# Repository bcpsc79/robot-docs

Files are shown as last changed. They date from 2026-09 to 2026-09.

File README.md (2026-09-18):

# BCPSC Robot

## 1. Project Overview

### 1.1 Description
The BCPSC Robot is a humanoid robot powered by AI, created by students from Bogura Cantonment Public School and College (BCPSC). Designed to act as an intelligent, interactive representative of the school, it can answer questions about BCPSC using a custom knowledge base, hold bilingual conversations (English and Bangla), recognize familiar faces, make eye contact, and use hand gestures.

### 1.2 Goals & Objectives
- Create an intelligent representative of BCPSC capable of answering questions using school data.
- Develop real skills in AI, robotics, electronics, and 3D design.
- Produce a fully functional humanoid robot to showcase student-led engineering in Bangladesh.
- Demonstrate that advanced robotics and AI are achievable with limited resources and strong determination.

### 1.3 Key Features
- **Bilingual Conversation:** Understands and speaks both English and Bangla natively using offline speech recognition models.
- **Face Recognition & Eye Tracking:** Uses real-time face detection to track faces and simulate natural gaze behavior.
- **Institutional Knowledge (RAG):** Answers questions specifically about BCPSC using a structured Retrieval-Augmented Generation dataset.
- **Natural Physical Expression:** Features a five-fingered hand with 20+ gestures, a physics-based moving jaw, and active eye servos.
- **AI Brain:** Runs a FastAPI microservice using Gemini's function-calling API to dynamically select tools (school lookup, news, hardware control).

---

## 2. Directory Structure & Documentation
This repository is organized into a pure file structure to separate domains. Each folder contains its own `README.md` documenting its architecture, challenges, solutions, learnings, and future improvements:

- **[`/Software/`](./Software/README.md)** - Documentation for the Raspberry Pi 5 vision, speech, AI brain, and API microservice.
- **[`/Firmware/`](./Firmware/README.md)** - Documentation for the C++ code running on the ESP32 and ESP8266 microcontrollers.
- **[`/Electronics/`](./Electronics/README.md)** - Documentation for the veroboard power distribution and voltage schemas.
- **[`/Mechanical Design/`](./Mechanical%20Design/README.md)** - Documentation for the 3D models and hybrid structural design.

---

## 3. Team & Contributions

- **Raiyan Bin Rashid:** Software Lead & AI System Development
- **Jotirmoy Bhowmik:** Software & System Integration
- **Farsad E Hossain:** Hardware Architecture, 3D Design & Mechanical Preparation
- **Naif Bin Nasim:** Hardware & Power Distribution
- **Fairuz Lubna Karim:** Visual Design & Presentation
- **Nahin Rahman:** Hardware Support

---

## 4. Project Timeline (211 Days)

- **Phase 1: Research & Planning (July - Aug 2025)** - Studied EZ-Robot/InMoov, defined robot capabilities, planned the 5-layer architecture.
- **Phase 2: Hardware Development (Aug - Oct 2025)** - Completed 3D modeling, printing, and assembly. Built the veroboard power system.
- **Phase 3: Software & AI Development (Sep - Dec 2025)** - Iterated Brain 1 (Ollama), Brain 2 (RAG & PostSTT), and Brain 3 (Gemini Function Calling API).
- **Phase 4: Integration & Testing (Nov 2025 - Jan 2026)** - Solved the audio feedback loop, connected Raspberry Pi to ESP32 over JSON protocol.
- **Phase 5: Optimization & Final Deployment (Jan - Feb 23, 2026)** - Codebase organized, docs written, ready for Science Fair exhibition.

---

## 5. Overarching Learnings
- **Continuous Coordination:** Because hardware and software were developed simultaneously, decisions in one domain constantly affected the other. The team learned to communicate changes across dependencies quickly and clearly.
- **Handling Leadership Gaps:** The team learned that a complex project doesn't pause when senior direction is unavailable; self-organization and peer-coordination are critical.
- **Ruthless Prioritization:** The requirement to have an exhibition-ready robot by a fixed date imposed discipline, teaching the team to defer non-essential improvements and focus purely on stability.

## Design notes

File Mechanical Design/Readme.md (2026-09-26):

# Mechanical Design Documentation

## Overview
The BCPSC Robot features a hybrid physical frame. Rather than an out-of-the-box kit, it is a custom-built chassis created by merging the best architectural qualities of two well-known open-source humanoid platforms: **EZ-Robot** and **InMoov**.
 
**Lead Mechanical Designer:** Farsad E Hossain

## Design Details

### 1. Hybrid 3D Printed Structure
- **Combining Platforms:** Because EZ-Robot and InMoov parts were not natively designed to fit together, the team redesigned joints, mounting points, and body proportions from scratch.
- **Iteration:** Creating a symmetrical, highly durable frame required multiple iterations of 3D modeling, test printing, and fit checking to ensure parts didn't collide.

### 2. Lower Base & Mobility
- **Weight Distribution:** The wheeled lower base was structurally designed and balanced to counter the high center of gravity generated by the humanoid upper torso and head.
- **Mobility:** Built around two DC motors with differential drive mechanisms to allow for pivoting and smooth forward motion.

### 3. Anatomical Features
- **Expressive Face:** The head houses an eye mechanism capable of panning and a jaw mechanism that physically simulates speech articulation.
- **Articulated Hand:** Features a fully assembled five-finger mechanical hand, structurally capable of performing over 20 distinct physical gestures.

## Challenges & Solutions
1. **Structural Merging:** Merging the two different platforms meant simple assembly wasn't an option. **Solution:** Complete structural redesign of the joints. Sustained rounds of physical fit testing were employed to correct imbalances before finalizing the printable files.

## Branches Reference
- `Components\3D Components\Robot 3d files`: Contains all the relevant 3D models and STL files used for printing.

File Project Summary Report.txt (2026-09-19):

Complete Project Summary Report
BCPSC Robot
Project Duration : 211 days

1

TABLE OF CONTENTS

2

1. INTRODUCTION

4

2. PROJECT OVERVIEW

5

3. PROJECT TIMELINE (211 DAYS BREAKDOWN)

6

4. SYSTEM ARCHITECTURE

7

5. PERSON -WISE CONTRIBUTIONS

11

6. TECHNICAL CHALLENGES FACED

14

7. SOLUTIONS & IMPROVEMENTS

15

8.

17

WHAT WE LEARNED FROM THIS PROJECT

9. FUTURE IMPROVEMENTS

20

10. CONCLUSION

21

1. INTRODUCTION
On July 27, 2025, a group of students from Bogura Cantonment Public School and College (BCPSC) started
building something unique for their school: a fully functional, AI -powered humanoid robot.
The BCPSC Robot was not created to meet a class requirement or copy an existing design. The team
believed that students from a school in Bogura, Bangladesh, could create something truly impressive. The
robot could recognize faces, understand speech in both
English and Bangla, respond intelligently to
questions, move its hands and eyes smoothly, and navigate its surroundings. This belief guided every
decision made over the next 211 days.
The goal of the project was to show that robotics and artificial intelligence are not just for well
-funded
research institutions or tech companies. By combining 3D
-printed hardware, open -source AI models,
locally hosted language systems, and custom electro
nics, the team aimed to prove that meaningful
engineering is achievable with limited resources, as long as there is enough determination and technical
skill.
The vision for the BCPSC Robot had three main objectives. First, to create a robot that could act as an
intelligent, interactive representative of the school, capable of answering questions about BCPSC's staff,
facilities, and institution using a knowledge base built specifically from school data. Second, to create a
platform for genuine learning, where each team member would develop real skills in areas they had never
explored before. Third, to produce something that could stand in an exhibition, showcasin
g both the
school and what student -led engineering in Bangladesh can achieve.
Bogura Cantonment Public School and College was the only sponsor and institutional supporter of this
project. Their support made the work possible, and the robot was designed from the start to carry the
institution's name and reputation.

3

2. PROJECT OVERVIEW
The BCPSC Robot is a humanoid robot powered by AI. It's designed to interact with people in a natural,
smart, and responsive way. It listens to questions in both English and Bangla, understands the inquiries,
and responds with speech. It recognizes familia r faces and greets them personally. It follows faces with
its eyes, moves its hands with gestures while speaking, and moves around using a wheeled base. When
asked about Bogura Cantonment Public School and College, including details about its staff, teache rs,
governing body, contact info, or institutional aspects, it answers from a structured knowledge base made
from BCPSC's own data. For general knowledge, current news, and questions outside the school
database, it connects through a layered AI system that can access online models when necessary and
works offline when the internet is not available.
In summary, the BCPSC Robot acts as an intelligent, bilingual, interactive assistant. It can hold
conversations, recognize who it is talking to, and represent its institution.

Key Features
The robot has several key features that set it apart from a basic demonstration project.
•

•

•

•

Bilingual conversation is central to its system. The robot understands and responds in both
English and Bangla. It uses offline speech recognition models for each language, running at the
same time in separate threads. The Bangla text -to-speech output uses a specific voice mode l for
natural-sounding speech.
Face recognition and eye tracking give the robot real awareness of the people in front of it.
YuNet face detection runs in real time on a Raspberry Pi 5. This information feeds into a
behavioral state machine that keeps the robot's eyes following whoever it looks at, complete with
blinkin g and subtle gaze shifts to make interactions feel more natural.
Institutional knowledge is managed through a Retrieval -Augmented Generation system based
entirely on BCPSC's own structured data. This includes staff lists, teacher information, governing
body records, and school contact details. The robot can accurately answer specific question s
about real people and departments without generating false information.
Natural physical expression comes from a five-fingered hand capable of over twenty different
gestures, a jaw that moves in a physics -based manner when speaking, and eye servos that move
smoothly per human gaze behavior. These parts are integrated with the AI system, allowing the
robot to gesture while talking and respond physically to its actions.

Hardware Summary
The robot's design is a hybrid created by analyzing and combining features from two open -source
humanoid platforms: EZ -Robot and InMoov. Every structural component was custom 3D modeled,
printed, tested, adjusted until the assembly met the team's standards for strength, symmetry, and
mechanical reliability.
The computing core operates on a Raspberry Pi 5 . This unit handles all AI processing, vision tasks,
speech recognition, and system coordination. A wheeled base provides mobility. It is controlled by an
ESP32 microcontroller that manages a PWM differential drive system, features a browser-based wireless
4

joystick interface, and has a hardware deadman switch that cuts motor power if the controller
disconnects.
Facial expressions are controlled by a second ESP32 , acting as the main controller. This device drives the
eye and jaw servos directly and sends hand gesture commands over WiFi to an ESP8266 , which manages
the five finger servos independently. The entire multi -microcontroller system communicates using serial
JSON commands and HTTP REST calls over a local WiFi network created by the ESP32.
Power is supplied through a custom -designed and hand -soldered veroboard circuit. This ensures the
correct voltage reaches every component, built from scratch to guarantee safe power delivery and circuit
reliability during operation.

Software Summary
The software architecture consists of five interconnected layers, from low -level motor control firmware to
cloud -connected AI services.
At the hardware level, C++ firmware on the ESP32 and ESP8266 microcontrollers manages all servo
control, motor operation, WiFi communication, and gesture execution. This is complex, with the eye
servo implementing four behavioral states (fixating, saccadin g, scanning, glancing) and employing
Exponential Moving Average smoothing and microsaccade simulation. The jaw's movement is based on a
physics model for realistic behavior.
The vision layer operates on the Raspberry Pi, using Python to create a detection -to-actuation pipeline.
This includes face detection with YuNet ONNX, face tracking with OpenCV's CSRT tracker, pose
estimation, gaze mapping, signal smoothing, and serial communication to th e servo controller, all
happening in a continuous real -time loop.
The speech layer runs two offline speech -to-text recognizers at once. It post-processes the recognized
text using fuzzy string matching to correct any misheard Bangla names and synthesizes responses using
offline text-to-speech models for both languages.
The AI brain evolved through three generations during the project. The final production version is a
FastAPI microservice built around Gemini's function -calling API. The language model automatically
selects the right tool —whether it's for a school database lookup, new s retrieval, web search, or weather—
based on user questions. This setup includes Redis caching, Server -Sent Events streaming for quick
responses, Prometheus metrics for monitoring, and a structured admin permission gate to prevent
hardware commands from ex ecuting without explicit authorization.
The school knowledge base is a structured dataset of BCPSC records, indexed by teacher’s name, role
and blood group . The dataset is collected from http://bcpsc.edu.bd/ It uses sentence -transformer
embeddings for semantic search with queries that do not match specific keywords.

5

3. PROJECT TIMELINE (~211 Days )
Phase 1: Research & Planning (July 27

– August 2025)

•

Studied existing humanoid robots (EZ -Robot, InMoov) to design a hybrid structure.

•

Defined robot capabilities: bilingual speech, face recognition, school knowledge, and physical
gestures.

•

Planned the five -layer architecture guiding hardware and software development.

Phase 2: Hardware Development (August

– October 2025)

•

Farsad completed 3D modeling, printing, and assembly of hybrid humanoid structure.

•

Naif built and soldered the custom veroboard power distribution system.

•

Nahin assisted with hardware installation, integration, and troubleshooting.

•

Wheeled base, body, and mechanical modules fully assembled by late October.

Phase 3: Software & AI Development (September

– December 2025)

•

Brain 1: Initial AI with local Ollama model, basic movement control, and face recognition.

•

Brain 2: Added BCPSC knowledge base, PostSTTProcessor for Bangla names, and multi
response cascade.

•

Brain 3: Production microservice using Gemini function -calling, Redis caching, SSE streaming,
and admin confirmation for hardware commands.

•

Raiyan implemented full hand assembly and coding integration for gestures.

Phase 4: Integration & Testing (November 2025

– January 2026)

•

Connected Raspberry Pi AI to ESP32 master controller using reliable serial JSON protocol.

•

Resolved audio feedback loop between TTS and STT.

•

Finalized dual -language offline STT and Bangla TTS synthesis.

Phase 5: Optimization & Final Deployment (January

6

-source AI

– February 23, 2026)

•

Codebase organized with separate virtual environments; documentation written.

•

Robot ready for exhibition: fully functional, bilingual, expressive, face -tracking, and AI -driven.

4. SYSTEM ARCHITE CTURE
The BCPSC Robot is built across five interconnected layers, spanning physical hardware at the base
and an AI-driven software brain at the top. Every layer communicates with the layers immediately
above and below it, forming a continuous pipeline from physical sensing to intelligent response. The
overall architecture was designed around three guiding principles: offline-first operation, hardware
safety, and modular separation of concerns, so that any single subsystem can be tested, repaired, or
upgraded independently.

4.1 Hardware Architecture
Microcontrollers
The robot's hardware intelligence is split among three microcontrollers. Each one has a specific role to
avoid any single controller slowing things down.
The main microcontroller is an ESP32, which acts as the master controller for the robot's expressive
systems. It manages the eye and jaw servos, processes incoming serial JSON commands from the
Raspberry Pi, and sends gesture instructions to the hand contr oller over HTTP. It works in both AP and
STA WiFi mode, meaning it serves as a wireless access point for the hand controller while also
connecting to the wider network. All commands from the Raspberry Pi are processed using ArduinoJson
and sent to the corr ect subsystem —eye, jaw, or hand—with a 100-millisecond lockout period applied
after each serial command to avoid conflicts between the web and serial interfaces.
The second microcontroller is an ESP8266, which focuses solely on hand gesture control. It runs a REST
API on port 80 and manages five individual finger servos —thumb, index, middle, ring, and little finger —
each mapped to fixed open and closed angles based on actual hardware testing. The ESP8266 has a
static IP address so the ESP32 master can find it easily.
The third microcontroller is another ESP32, which handles the drive system. It creates a WiFi access
point and provides a browser -based dual -joystick controller interface to any connected device. It
controls two DC drive motors using PWM for differential d rive. It includes a hardware deadman switch: if
no device connects to its access point for more than 500 milliseconds, the motors stop immediately and
movement is disabled. This design prevents the robot from moving on its own or rolling if the operator
loses connection.
A Raspberry Pi 5 is positioned above the microcontroller layer and serves as the main processor for
vision and AI tasks. It communicates downward to the ESP32 master using serial USB and a structured
NDJSON command protocol with acknowledgment and retry lo gic.
Power System
The hardware team designed and built the power distribution system from the ground up. They created
a custom Veroboard circuit to organize all power connections safely and make sure each component
gets the right operating voltage. The system uses a series battery setup to provide the voltage levels
needed by the drive motors, while a buck converter lowers the voltage to s afer levels for the
microcontrollers and servo motors. Strict wiring practices were followed throughout, since one wrong
7

connection in such a complex circuit could damage the entire system. The team conducted multiple
tests to confirm connection integrity before attaching powered components.
Motors and Servos
The robot uses two DC motors for movement, controlled by an H -bridge driver. This setup allows
management of both direction and speed through four PWM pins. Steering is done via differential drive —
reducing the PWM output on one side compared to the other c auses the robot to turn while still moving
forward.
The eye servo pans left and right over a calibrated range, driven by an Exponential Moving Average
smoothing algorithm that adjusts its responsiveness based on the robot's current behavior, creating
natural -looking gaze movement instead of mechanical snapp ing. The jaw servo uses a physics -based
motion model with velocity accumulation and damping, resulting in realistic mouth movement during
speech. The five hand servos operate independently, each moving to precise angles to create distinct
gestures from a l ibrary of over twenty programmed positions.
Mechanical Structure
The physical body of the BCPSC Robot is a hybrid design based on two established open -source
humanoid platforms —EZ -Robot and InMoov. It combines the best structural features of each into one
unified frame. All structural components, custom brackets, and bo dy panels were designed in 3D
modeling software and printed through several iterations, with fit testing and dimensional adjustments
made along the way.
The bottom base was designed with a focus on weight distribution, as the humanoid upper body creates
a high center of gravity that needs to be balanced by the wheeled base for stable movement. The overall
assembly underwent multiple rounds of symmetry chec ks and structural reinforcement to ensure
smooth mechanical operation across all joints and moving parts .

4.2 Software Architecture
Speech -to-Text (STT)
The speech recognition system runs two simultaneous recognizers within a single audio capture loop.
This setup allows the robot to understand input in both English and Bangla, without needing the speaker
to announce their language beforehand. English recognition is managed by Vosk, utilizing a Kaldi
acoustic model that operates entirely offline. Bangla recognition works in a parallel daemon thread
using the BanglaSpeech2Text library, also offline. During startup, the system performs ambient no ise
calibration to set appropriate energy thresholds for the microphone. A key challenge encountered
during development was audio feedback, as the robot's own TTS output was detected by the
microphone as new speech input. Careful management of audio stream timing and the relationship
between playback and capture processes resolved this issue.
STT systems often mishear Bangla proper nouns. To address this, a dedicated PostSTTProcessor
processes every recognition output before it reaches the AI brain. This processor applies three correction
strategies in sequence: Levenshtein edit distance scorin g, SequenceMatcher longest -common 8

subsequence ratio, and optional semantic embedding matching using sentence transformers. The
combined score from these methods is weighted and compared against a threshold before the corrected
text is forwarded. This step is crucial for accurate name looku ps in the BCPSC staff database.

AI Brain
The AI brain has evolved through three distinct generations during the project. The first generation relied
on a fully offline Ollama local language model with a regex -based intent recognition engine that covered
nine intent types in English and Bangla Uni code patterns. While it was functional, it lacked awareness of
school -specific information.
The second generation introduced a structured knowledge base along with a multi -source response
method. The system first searches the BCPSC database, then attempts an offline knowledge layer of
hardcoded facts, and only calls the Gemini 2.0 Flash API as a last resort. Each response includes a source
label that shows which pipeline generated it, ensuring that the system's reasoning is transparent.
The third and current generation is built as a FastAPI microservice centered on Gemini's native function calling capability. Instead of pre -classifying every query in code, the language model reads the user's
input and creates a structured function call. I t selects from registered tools, including school database
lookup, news retrieval, web search, weather, and hardware device control. The microservice executes
the selected tool, sends the result back to the model, and the model provides the final natural -language
response. Hardware control commands are queued and need separate admin confirmation before
execution, ensuring a safety measure between the AI layer and the physical robot’s movement.
Retrieval -Augmented Generation (RAG)
The RAG system gives the robot accurate, grounded knowledge about BCPSC. The knowledge base
consists of structured JSON datasets that include staff rosters, teacher lists for both the school and
college sections, governing body members, and institutional c ontact details. At startup, the system
builds two in -memory indexes from this data: a role index that maps job titles to records and a name
index that maps lowercase names to records for quick lookups. If an exact match isn’t found, the system
uses semanti c search with sentence -transformer embeddings and cosine similarity scoring. This setup
allows common queries, like finding a teacher by name or retrieving contact information, to be
answered in milliseconds without any API call. Uncommon or unclear querie s still get meaningful
responses through semantic retrieval.
Text-to-Speech (TTS)
The TTS system supports voice output in both English and Bangla. Bangla synthesis uses the Coqui TTS
library with the mobassir94/bangla -tts model. A text cleaning pipeline removes all non -Bangla Unicode
characters before synthesis to prevent garbled output from mixed-script input. Synthesized audio is
cached using a hash of the cleaned text, meaning repeated phrases, like greetings and standard
responses, load instantly from cache rather than being re -synthesized. For higher -quality output, a
quantized GGUF Bangla TTS model runs through llama.cpp, striking a good balance between voice
9

quality and file size on limited hardware. Synthesis runs in a background thread to avoid blocking the
main conversation loop while generating audio.
Vision
The vision system comprises a multi -stage pipeline designed to operate at real -time speeds on the
Raspberry Pi 5. Frames from the camera are first sent to a YuNet face detector running as an ONNX
model, which functions at about ten to fifteen frames per se cond at 320 by 240 resolution. This
resolution was chosen after testing confirmed that 640 by 480 caused unacceptable latency on ARM
hardware. Between detection frames, a CSRT tracker keeps track of the last known face position,
preventing visual output fr om flickering when the detector misses a single frame.
A PersonSelector module identifies the most relevant face in scenes with several people. It uses face size,
proximity to the center of the frame, and tracking continuity for this purpose. A PoseEstimator then
derives the subject's approximate gaze directio n from facial landmark geometry. A GazeMapper
translates this into a target servo angle. A final smoothing filter —using a critically -damped model rather
than simple exponential smoothing, which caused servo oscillation —converts the mapped angle into a
stable command sent over serial to the ESP32.
The system maintains three behavioral states: active tracking when a face is detected, idle sweep with
randomized blink timing when no face is present, and a smooth return -to-center transition between the
two. Face recognition runs separately using DeepFac e with Facenet512, creating 512 -dimensional face
embeddings that are matched against a database of known individuals for identity identification.
Backend API
The backend operates as a FastAPI microservice that provides a versioned REST and streaming API for all
robot intelligence functions. The primary chat endpoint returns responses via Server -Sent Events
streaming, with a target latency of under 200 milliseco nds for cached queries. Redis caching, along with
an in-memory fallback, stores recent responses with short time -to-live values to avoid stale answers
while significantly speeding up repeated queries. Asynchronous parallel tool execution lets multiple
Gemini function calls run at the same time using Python's asyncio framework when the model requests
more than one tool at once. Prometheus metrics are available at a dedicated endpoint, tracking request
counts, latency histograms, and tool call frequency for o bservability. The entire service is containerized
using Docker Compose with a Redis sidecar, and Kubernetes manifests are available for production
deployment. A complete test suite includes unit tests with mocked Gemini responses and integration
tests that validate end -to-end latency against defined performance targets.

10

5. PERSON -WISE CONTRIBUTION
5.1 Raiyan Bin Rashid
Software Lead & AI System Development
Areas of Work:
•

Designed and implemented the full AI interaction pipeline (STT → AI processing → TTS)

•

Integrated Text -to-Speech with natural voice output

•

Built and rebuilt the Robot Brain system (multiple versions)

•

Implemented RAG for school -specific knowledge

•

Developed a FastAPI -based Robot Brain microservice with structured API endpoints

•

Connected vision tracking with eye movement control

•

Managed Raspberry Pi deployment and microcontroller communication

•

Made the full hand assembly and completed the hand movement coding

Major Contributions:
•

Modular AI system design for smooth real -time conversation

•

Reduced latency and improved response stability for live demos

•

Safety control before executing hardware commands

•

Structured system prompts with tone, limitations, and fallback behavior

Challenges:
•

Managing real-time listening and speaking without overlap

•

Handling noisy audio and misrecognized Bangla names

•

Preventing incorrect AI -generated information

•

Maintaining system stability during live demonstrations

5.2 Jotirmoy Bhowmik
Software & System Integration
Areas of Work:

11

•

Movement Control System (motor control logic and command execution flow)

•

Face Recognition System development and integration

•

Hardware –Software integration

•

Assisted in Body Assembly

•

Technical support to team members

Major Contributions:
•

Ensured stable and responsive movement control

•

Integrated face recognition for known person detection

•

Connected software with hardware so commands work correctly

Challenges:
•

Hardware -software synchronization

•

Multiple iterations for movement calibration

•

Optimizing real -time face recognition performance

•

Efficient system design with limited resources

5.3 Farsad E Hossain
Hardware Architecture, 3D Design & Mechanical Preparation
Areas of Work:
•

Full 3D modeling and structural design of robot body

•

3D printing of all structural and custom parts

•

Bottom base construction and wheel system design

•

Mechanical integration of all hardware modules

•

Architecture modification and structural improvements

Major Contributions:
•

Designed a hybrid structure from EZ -Robot and InMoov

•

Printed and modified custom parts for strength and fit

•

Constructed the bottom base with proper balance and weight distribution

•

Performed multiple testing rounds and structural corrections

Challenges:
•

Combining two robot structures into one cohesive system

•

Maintaining symmetry, durability, and smooth movement

•

Independent hardware preparation required careful problem -solving

5.4 Naif Bin Nasim
Hardware & Power Distribution
12

Areas of Work:
•

Robot movement hardware setup

•

Hand movement hardware support

•

Full power distribution system design and implementation

•

Hand -soldered veroboard circuit from scratch

Major Contributions:
•

Built a safe and organized power distribution system

•

Ensured correct wiring for all motors and components

•

Maintained circuit safety during testing

Challenges:
•

Small wiring errors could damage the circuit

5.5 Fairuz Lubna Karim
Visual Design & Presentation
Areas of Work:
•

Overall visual design of the robot

•

Preparing the robot for exhibition display

Major Contributions:
•

Made the robot presentable in the Science Fair 2025 at BCPSC

5.6 Nahin Rahman
Hardware Support
Areas of Work:
•

Assisted in hardware preparation and assembly

•

Helped with installation and troubleshooting

Major Contributions:
•

Supported hands -on hardware tasks

•

Helped complete hardware setup within project timeline

Challenges:
•
•

13

Limited guidance at times; team had to self -coordinate

6. TECHNICAL CHALLENGES FACED
Hardware Challenges
The biggest hardware challenge was merging two different open -source humanoid platforms, EZ -Robot
and InMoov, into one physical structure. These systems were not designed to work together, so
combining them required a complete redesign of joints, mounting points, and proportions instead of
just simple assembly. Keeping the structure symmetrical while ensuring durability and smooth
movement at all joints involved several rounds of 3D printing, physical testing, corrections, and
reprinting before the frame me t acceptable standards.
Software Challenges
The main software challenge was audio feedback. The robot's text -to-speech voice was being picked up
by the microphone and processed as new input, creating a loop that interrupted conversations. Solving
this issue needed careful timing and management of th e playback and capture processes. Another
related challenge was the consistent misrecognition of Bangla proper nouns by the speech -to-text
engine, which made name lookups against the BCPSC database unreliable until a dedicated correction
layer was created and integrated.
AI Challenges
The key AI challenge was stopping the language model from producing incorrect or made -up
information about BCPSC, including details about its staff and structure. Since general -purpose
language models lack specific knowledge about a school in Bogura, Bangl adesh, each school -related
response had to rely on the local knowledge base through RAG before reaching the model. Establishing
reliable confidence thresholds to determine when the RAG result was good enough and when to switch
to an online API required ext ensive tuning. Creating a system that detected intent and language equally
well in English and Bangla Unicode without misrouting queries added more complexity.
Power and Safety Issues
Designing a safe power distribution system for a robot with multiple microcontrollers, servo motors, and
DC motors, each needing different voltage and current, was a critical engineering task. A single wiring
error could damage the entire circuit. Several connection errors were found and fixed during testing
before the system was stable and safe. On the software side, a hardware deadman switch was included
in the drive system to automatically cut motor power if the wireless controller connection dropped,
preventing the robot from moving without an active operator.
Resource Limitations
The entire project operated under tight resource constraints. Hardware components, computing power,
and development time were limited, so every decision had real costs. Running computer vision tasks on
a Raspberry Pi 5 required careful choices about resolu tion—using 320 by 240 pixels instead of 640 by
480—because the higher resolution caused latency that made real -time tracking impossible on ARM
hardware. The need to maintain separate Python virtual environments due to conflicts among computer
vision, audio , and AI libraries added to the deployment complexity. Throughout the project, the team
14

consistently sought solutions that were not only functional but also lightweight and efficient enough to
run reliably on the available hardware.

7. Solutions & Improvements
7.1 How Problems Were Identified
Most problems in the BCPSC Robot project were identified through direct testing rather than theoretical
analysis. Hardware issues surfaced during physical assembly and powered testing rounds, where
incorrect wiring, poor servo calibration, or structural im balance produced immediate and observable
failures. Software issues emerged during live system runs — the audio feedback loop, for instance, was
not anticipated during design but became immediately apparent the first time TTS and STT ran
simultaneously. AI accuracy problems were discovered through test queries, where the language
model's tendency to generate plausible but incorrect information about BCPSC became clear as soon as
school -specific questions were asked. In each case, the team documented what fa iled, traced it to its
root cause, and built a targeted solution rather than applying broad workarounds.
7.2 How Problems Were Solved
The audio feedback problem was resolved by managing the timing relationship between the TTS
playback process and the STT microphone capture process, ensuring the recognizer was not actively
listening while the robot was speaking. The Bangla name misrecogni tion problem was solved by building
a dedicated PostSTTProcessor that applied three complementary string similarity algorithms
—
Levenshtein distance, SequenceMatcher ratio, and semantic embedding matching — in sequence,
correcting STT output before it rea ched any name lookup or database query. Hardware race conditions
between the serial interface and the web interface were resolved by implementing a 100 -millisecond
lockout window after every serial command, giving the hardware time to settle before accepti ng further
instructions. The eye -tracking flicker problem was solved by introducing a CSRT tracker running
between detection frames, maintaining continuity on the last known face position when the detector
momentarily failed. Power safety was addressed thr ough a purpose -built veroboard circuit with
organized, verified wiring, combined with a software deadman switch that cut motor power
automatically upon controller disconnection.
7.3 What Improved Over Time
The project showed consistent improvement in three areas. Response accuracy improved as the
knowledge base matured — early versions of the robot had no school -specific knowledge and would
fabricate answers, while later versions grounded every BCPSC -related response in verified data through
RAG. System stability improved as the serial communication protocol was hardened with ACK and retry
logic, and as audio pipeline timing was refined. Response speed improved through the introduction of
Redis caching, offli ne-first knowledge lookup, and audio caching for repeated TTS phrases, reducing
latency on predictable queries to near -instant levels.
7.4 Brain Version 1 to Version 3 Evolution
Brain Version 1 — was fully offline and deterministic. All user input passed through a regex -based intent
recognition engine that classified queries into one of nine intent types in both English and Bangla, then
15

routed each to a dedicated handler. Responses were generated by a local Ollama language model
running the Gemma 2B model on -device. This version was functional and required no internet
connection, but it had a fundamental limitation: the model had no knowl edge of BCPSC and would
produce confident but inaccurate answers to any school -specific question.
Brain Version 2 — addressed this by introducing a structured RAG knowledge base built from real BCPSC
data. A QueryClassifier detected the language and type of each query, routing it through a cascade —
first to the school database, then to an offline knowledge layer of har dcoded facts, then to Ollama for
enhancement, and finally to the Gemini API or News API when all local sources were insufficient. The
PostSTTProcessor was added at this stage to correct misheard Bangla names before they reached the
database. Each response carried a source and pipeline label so the system's reasoning path was always
transparent. The limitation of this version was that the code itself was still making all routing decisions
— the language model had no agency over which tool or data source to c onsult.
Brain Version 3 — resolved this by handing decision -making authority to the model itself through
Gemini's native function -calling API. Rather than the code pre -classifying every query, the model reads
the user's message and emits a structured function call selecting from r egistered tools — school
database lookup, weather, news, web search, and hardware device control. The microservice executes
the selected tool, returns the result, and the model produces the final response within a single streaming
cycle. This version added production infrastructure that the earlier versions lacked entirely: SSE
streaming for low -latency output, Redis caching, Prometheus observability metrics, an admin
confirmation gate for hardware commands, Docker containerization, and a full test suite. T he
progression across all three versions reflects the project's central lesson — begin with deterministic,
code-controlled logic to establish reliability, then progressively transfer agency to the model as the
infrastructure around it matures.

16

8. What We Learned From This Project
8.1 Technical Learning
Raiyan Bin Rashid — Software Lead
Raiyan's technical growth across the 211 days of this project was the most broad in scope, given that he
was responsible for every layer of the software stack. He developed practical proficiency in building
production -grade Python backend services using Fa stAPI, managing asynchronous programming with
asyncio, and structuring REST and streaming APIs for real -world deployment. He learned how Retrieval Augmented Generation works not as an abstract concept but as an engineering problem — how to
structure a know ledge base, build embedding indexes, tune confidence thresholds, and decide when
local retrieval is sufficient versus when to escalate to an online model. He gained hands -on experience
with the Gemini function -calling API and understood the fundamental dif ference between code controlled intent routing and model -controlled tool selection. His work across three generations of the
robot brain gave him direct experience in system evolution — understanding why an architecture that
works at one level of complexity breaks at the next, and how to rebuild thoughtfully rather than patch
repeatedly.
Jotirmoy Bhowmik — Software & Integration
Jotirmoy learned how motor control logic translates from code to physical behavior — that a PWM value
on a screen corresponds to a real force on a wheel, and that the relationship between the two requires
calibration, testing, and iteration. He gained prac tical experience in hardware -software integration,
understanding that the boundary between a microcontroller and a software system is not clean and
requires careful protocol design on both sides. His work on face recognition gave him exposure to
computer v ision pipelines, embedding -based identity matching, and the performance constraints of
running inference in real time on limited hardware.
Farsad E Hossain — Hardware & 3D Design
Farsad developed the most specialized technical skillset on the team. He learned professional 3D
modeling and structural design for robotics applications — not decorative modeling, but functional
design where every dimension affects whether a part fits, ho lds weight, and moves correctly. He learned
the full 3D printing workflow: designing for printability, accounting for material tolerances, identifying
structural weak points, and iterating through multiple versions of the same part until it performed
reliably. Studying EZ -Robot and InMoov gave him a working understanding of how established
humanoid platforms are engineered, and combining them into a hybrid structure taught him how to
evaluate, adapt, and improve existing designs rather than simply replicate them.
Naif Bin Nasim — Power & Electronics
Naif developed practical skills in electronics and circuit design that are difficult to acquire outside of a
real project with real consequences. He learned how to read and design power distribution circuits, how
to solder a veroboard from scratch, and how to organize a multi -component wiring system safely and
clearly. He learned how different components — microcontrollers, servo motors, DC motors — have
different voltage and current requirements, and how a distribution system must account for all of them
17

simultaneously. The testing phase, where connection mistakes were identified and corrected without
damaging the overall circuit, gave him direct experience in hardware fault diagnosis and safe
troubleshooting practice.
Nahin Rahman — Hardware Support
Nahin gained broad practical exposure to hardware assembly and installation across multiple systems,
developing hands -on familiarity with the physical construction of a complex robot. He learned how to
contribute effectively to a technical project without having primary ownership of any single system, and
how to identify problems and escalate them appropriately during testing.
8.2 Teamwork Learning
Coordination
The BCPSC Robot required hardware and software to be developed simultaneously by different people,
which meant that decisions made in one domain constantly affected the other. The team learned that
coordination in this kind of project is not a one -time planning activity but a continuous process. When
Farsad modified a structural dimension, it affected where Naif could route wiring, which affected where
Jotirmoy could place sensors, which affected what Raiyan could assume about camera positioning.
Learning t o communicate changes across these dependencies — quickly and clearly — was a skill the
team developed through necessity rather than instruction.
Task Distribution
Early in the project, task boundaries were not always clearly defined, which led to occasional duplication
of effort and gaps in ownership. Over time the team naturally settled into a structure where hardware
and software responsibilities were separated, a nd within each domain, individuals took clear ownership
of specific subsystems. This organic distribution proved effective because it matched each person's
emerging strengths to the work that needed doing, rather than assigning roles based purely on initia l
preference.
Handling Leadership Gaps
There were periods during the project when senior direction was limited and team members had to take
initiative without waiting for instruction. This was particularly noted in the hardware team, where
assembly and troubleshooting work continued through coo rdination among peers rather than top -down
management. The team learned that a project of this complexity does not pause when a leader is
unavailable, and that the ability to self -organize and make reasonable decisions independently is as
important as any technical skill.
Working Under Deadline
The requirement to have a working, exhibition -ready robot by a fixed date imposed a discipline on the
project that no internal process could have replicated. The team learned to prioritize ruthlessly —
deferring improvements that were desirable but not ess ential, and concentrating effort on whatever was
most likely to fail under exhibition conditions. They learned that a robot that works reliably at eighty
18

percent of its intended capability is more valuable at a demonstration than one that works brilliantly half
the time.
8.3 Personal Growth
Beyond technical skills and teamwork, the project produced a kind of personal growth in each member
that is harder to quantify but no less real. Every member of the team encountered problems they did not
know how to solve at the moment they encountered the m, and solved them anyway. Farsad completed
the entire mechanical construction independently, which required not just skill but sustained self reliance over months of work. Raiyan rebuilt the robot's AI brain three times, which required the
willingness to acknowledge that a previous version was insufficient and start again with a clearer
understanding. Naif worked in a domain where a single mistake could undo weeks of work, and learned
to carry that responsibility calmly. Jotirmoy operated at the boundary b etween two worlds — software
and hardware — where the rules of each domain sometimes conflict, and learned to navigate that
ambiguity without losing ground in either direction.
The project also gave the entire team a realistic understanding of what engineering actually involves. It
is not a linear process from idea to finished product. It is a repeated cycle of building, testing, failing,
understanding why, and building again — and the willingness to complete that cycle without losing
motivation is perhaps the most important thing any of them took away from the 211 days they spent
building the BCPSC Robot.

19

9. FUTUR E IMPROVEMENTS
9.1 More Natural Movement
The current movement system is functional but operates within visible mechanical constraints. Future
development should focus on making the robot's physical behavior feel more organic and less
predictable. This includes expanding the hand gesture library w ith smoother transition animations
between positions, introducing coordinated upper -body movement so that arm, hand, and head motion
occur together in response to speech rather than independently, and refining the walking or drive
system to produce smoothe r acceleration and deceleration curves. The eye and jaw physics models,
while already implementing velocity and damping, could be further tuned with more sophisticated
behavioral patterns — longer fixation durations, more varied saccade amplitudes, and con text-aware
gaze direction that responds to where sound is coming from rather than purely where a face appears
visually.
9.2 Better Speech Quality
The current Bangla TTS output, while functional, does not yet match the naturalness of a human
speaker. On the recognition side, the STT system would benefit from a fine -tuned Bangla acoustic model
trained on local accents and school -context vocabulary, which would reduce the frequency of proper
noun misrecognitions and decrease dependence on the post -proces sing correction layer. Implementing
speaker diarization — the ability to distinguish between different speakers during a conversation —
would also allow the robot to maintain more coherent multi -person interactions during public
demonstrations.
9.3 Improved Battery System
The current power system, while safely designed, requires manual charging and does not provide the
robot or its operator with real -time information about remaining capacity. A meaningful improvement
would be the integration of a battery management system t hat monitors cell voltage, estimates
remaining runtime, and communicates charge level to the software layer so the robot can alert
operators before power becomes critically low. Moving toward a hot -swappable battery configuration —
where a depleted battery pack can be replaced without powering down the entire system — would
significantly improve the robot's suitability for extended exhibition use. Exploring higher energy -density
battery options and optimizing the power draw of the servo and motor systems wo uld further extend
operational duration between charges.
9.4 Mobile Application Control
The current control interface is browser -based and primarily intended for technical operators. A
dedicated mobile application would make the robot significantly more accessible to non -technical users
including teachers, administrative staff, and students. The application should provide real -time status
monitoring showing the robot's current operational state, active speech recognition language, and
battery level. It should allow authorized users to update the knowledge base, add new known faces to
the recognition database, and configure behavioral parameters without accessing the underlying code.
For demonstrations and exhibitions, a simplified presentation mode within the application could allow a
20

designated operator to cue specific responses or direct the robot's attention, providing greater control
over the interaction experience in front of an audience.

10. CONCLUSION
On July 27, 2025, a group of students from Bogura Cantonment Public School and College sat down with
an idea that had no guarantee of success. Two hundred and eleven days later, they had built a fully
functional AI -powered humanoid robot — one capable of r ecognizing faces, understanding speech in
two languages, answering questions about its own institution, moving its hands and eyes with natural
fluid motion, and holding a real conversation with the people standing in front of it.
The journey was not straightforward. The team rebuilt the robot's AI brain three times. They redesigned
structural components that failed under physical testing. They debugged audio pipelines at midnight,
traced wiring faults in live circuits, and rewrote software systems they had already considered finished.
Every major capability the robot demonstrates today exists because a specific problem was
encountered, understood, and solved — not because the path was clear from the beginning.
What the BCPSC Robot represents is therefore something larger than the robot itself. It is a
demonstration that advanced engineering is not the exclusive domain of universities, technology
companies, or well -funded research institutions. It is proof that s tudents from a school in Bogura,
Bangladesh, working with limited resources, shared hardware, and their own developing skills, can
produce something technically sophisticated and genuinely meaningful. The project touched embedded
systems, computer vision, natural language processing, multilingual speech, electronics, structural
design, and production software architecture — not superficially, but with the depth that comes from
building something that actually had to work.
For Bogura Cantonment Public School and College, this project carries particular significance. The robot
was built to represent the institution — to carry its name, answer questions about its people, and stand
as evidence of what its students are capable o f. It sets a precedent for the kind of work that is possible
within these walls, and establishes a foundation that future students can build upon, improve, and take
further. The knowledge, the codebase, the hardware designs, and the lessons documented in t his report
do not belong only to the team that created them. They belong to the institution, and to every student
who comes after.
The BCPSC Robot is not a finished product. It is a beginning .

The End
21

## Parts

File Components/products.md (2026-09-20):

| Sl | Voucher Number | Shop Name | Product Description | Amount | Remarks |
| -: | ---: | --- | --- | ---: | --- |
|  1 | 1 | Robotics BD | Raspberry Pi, Camera, Touch Display, Speaker | 33,785.00 | |
| | | | Courier Charge | 110.00 | |
|  2 | 2 | Robotics BD | Wheel, Servo Motor, Servo Tester, Soldering Station tip set | 7,553.00 | |
|  3 | 3 | Spider Technologies | 3D Print | 17,234.00 | |
|  4 | 4 | Radio Gear BD | 300 RPM Gear Motor, Motor Gear | 6,130.00 | |
|  5 | 5 | Alamgir Mechanariz | Screw | 120.00 | |
|  6 | 6 | Mobile City | Ulamzi UM, USB Converter | 1,650.00 | |
|  7 | 7 | Global Brand PLC | Power Bank | 5,800.00 | |
|  8 | 8 | Shourov Trades | Mg - 996R, Type-B, 3.7 B+ | 1,415.00 | |
|  9 | 9 | Shifa Electronics | Battery BMS | 470.00 | |
| 10 | 10 | Shena Somvhar | Super Glue | 40.00 | |
| 11 | 11 | Zahid Engineering Workshop | SS Pipe, Screw, Hole and Assembly | 760.00 | |
| 12 | 12 | RR Kabel | Cable | 50.00 | |
| 13 | 13 | Niloy Electronics | Cable | 45.00 | |
| 14 | 14 | Momin Electronics | Battery, DC Socket, Black Switch | 940.00 | |
| 15 | 15 | Shourov Trades | 4S 10A BMS | 150.00 | |
| 16 | 16 | Mobile City | Remax Converter | 220.00 | |
| 17 | 17 | Shourov Trades | ESP 32, ESP Cam, Breadboard and wires | 5,600.00 | |
| 18 | 18 | Robotics BD | Motor Mount, Camera Cable, USB Micro-B Cable, Shipping Cost | 1,610.00 | |
| 19 | 19 | Anysphare INC | Cursor AI Pro (1 Month) | 2,500.00 | |
| 20 | 20 | Google Cloud | Text-to-speech, speech-to-text, and large language model API. | 650.00 | |
| 21 | 21 | Shifa Electronics | ESP32 Dev Module | 550.00 | |
| 22 | 22 | Spider Technologies | 3D Printing (Hand and Head parts) | 1,100.00 | |
| 23 | 23 | Robotics BD | ESP32 Dev Module | 500.00 | |
| | | | Courier Charges | 110.00 | |
| | | | **Total Expenditure** | **89,092.00** | |

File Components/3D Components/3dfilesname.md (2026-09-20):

| /Body | /Left Arm | | |
| --- | --- | --- | --- |
| 1 | ClaviBackV2 | Left Arm/Fingers | |
| 2 | ClaviBackV2 (1) | 1 | Auriculaire3 |
| 3 | ClaviFrontV2 | 2 | Index3 |
| 4 | ClaviFrontV2 (1) | 3 | leftthumb5 |
| 5 | HomLowBackV3 | 4 | Majeure3 |
| 6 | HomLowBackV3 (1) | 5 | ringfinger3 |
| 7 | HomLowFront-V1 | Left Arm/Wrist and Forearm  | |
| 8 | HomLowFront-V1 (1) | 1 | Bolt_entretoise7 Black |
| 9 | homplateback+V1 | 2 | LeftCableHolderWristV5 |
| 10 | homplateback-V1 | 3 | LeftRobCableBackV3 Black  |
| 11 | homplatefront+V1 | 4 | LeftRobCableFrontV3 Black |
| 12 | homplatefront-V1 | 5 | LeftRobCapV2 |
| 13 | KinectSideBackV2 | 6 | LeftRobpart2V4 |
| 14 | KinectSideBackV2 (1) | 7 | LeftRobpart3V4 |
| 15 | KinectSideHolderV1 | 8 | LeftRobpart4V4 |
| 16 | KinectSideHolderV1 (1) | 9 | LeftRobpart5V4 |
| 17 | SternumV1 | 10 | LeftRobServoBedV6 black |
| /Face Jaw and Head | 11 | LeftRotawrist1V4 | |
| 1 | 2xEyeBallFullV2 | 12 | LeftRotaWrist2V3 |
| 2 | EyeBallSupportLifeCam+HDLeftV1  | 13 | LeftTensionerV1 |
| 3 | EyeBallSupportLifeCam+HDRightV1 | 14 | LeftWristlargeV4 |
| 4 | EyeglassV4 | 15 | LeftWristsmallV4 |
| 5 | EyeHingeCurveV1 | 16 | RotaWrist3V3 |
| 6 | EyeHingeV2 | 17 | servo_pulleyx5 |
| 7 | EyeHolderV1 | 18 | WristGearsV5 Black |
| 8 | EyePlateLeftV1 | Left Arm/Shoulder and Bicep | |
| 9 | EyePlateRightV1 | 1 | elbowshaftgearV1 Black |
| 10 | EyeSupportV5 | 2 | GearholderV1 |
| 11 | EyeToNoseV5 | 3 | gearPotentioV1 Black |
| 12 | FaceHolderV4 | 4 | HighArmSideV3 |
| 13 | GearHolderV2 | 5 | HighArmSideV3 - Copy |
| 14 | JawHingeV1 | 6 | LeftPivotcenterV3 |
| 15 | JawHingeV3 | 7 | LeftPivMitV2 |
| 16 | JawPistonV1 | 8 | LeftRotcenterV2 |
| 17 | JawSupportV1 | 9 | LeftRottitlV4 |
| 18 | JawV4 | 10 | lowarmsideV1 |
| 19 | LowBackV5 | 11 | lowarmsideV1 - Copy |
| 20 | MainGearV2 | 12 | PistonanticlockV2 Black |
| 21 | NeckBoltsV2 | 13 | PistonbaseantV2 |
| 22 | NeckJointLowerV5 | 14 | PivConnectorV1 |
| 23 | NeckPlateHighV2 | 15 | PivConnectorV1 - Copy |
| 24 | NeckPlateV2 | 16 | PivPotentioRoundV3 |
| 25 | NeckV3 | 17 | PivPotentioRoundV3(Copy)  |
| 26 | RingV2 | 18 | reinforcerV1 |
| 27 | ServoShearV2 | 19 | reinforcerV1 - Copy |
| 28 | SideHeardV5 | 20 | RibbonPusherV1 |
| 29 | SkullServoFixV1 | 21 | RotGearV6 Black |
| 30 | ThroatHolderV2 | 22 | RotMitV3 |
| 31 | ThroatHoleV3 | 23 | RotwormV5 Black |
| 32 | TopBackskullV4 | 24 | servobaseV1 Black |
| 33 | TopMouthV4 | 25 | servoholderV1 Black |
| 34 | TopskullLeftV4 | 26 | spacerV1 |
| 35 | TopskullRightV4 | | |
| Right Arm | | | |
| Right Arm/Fingers | Right Arm/Shoulder and Bicep | | |
| 1 | Auriculaire3 | 1 | elbowshaftgearV1 |
| 2 | Index3 | 2 | HighArmSideV3 |
| 3 | leftthumb5 | 3 | HighArmSideV3 (2) |
| 4 | Majeure3 | 4 | LowArmSideV3 |
| 5 | ringfinger3 | 5 | LowArmSideV3 (1) |
| Right Arm/Wrist and Forearm | 6 | PivcenterV3 | |
| 1 | Bolt_entretoise7 black | 7 | PivConnectorV1 |
| 2 | CableHolderWristV5 | 8 | PivConnectorV1 (2) |
| 3 | RobCableBackV3 black | 9 | PivMitV2 |
| 4 | RobCableFrontV3 black | 10 | ReinforcerV2 |
| 5 | robcap3V2 | 11 | ReinforcerV2 (1) |
| 6 | robpart2V4 | 12 | RotCenterV3 |
| 7 | robpart3V4 | 13 | RotTitlV4 |
| 8 | robpart4V4 | 14 | spacerV1 |
| 9 | robpart5V4 | | |
| 10 | RobServoBedV6 black | | |
| 11 | RotaWrist1V4 | | |
| 12 | RotaWrist2V3 | | |
| 13 | RotaWrist3V3 | | |
| 14 | servo_pulleyx5 | | |
| 15 | TensionerRightV1 | | |
| 16 | WristGearsV5 black | | |
| 17 | WristlargeV4 | | |
| 18 | WristsmallV4 | | |

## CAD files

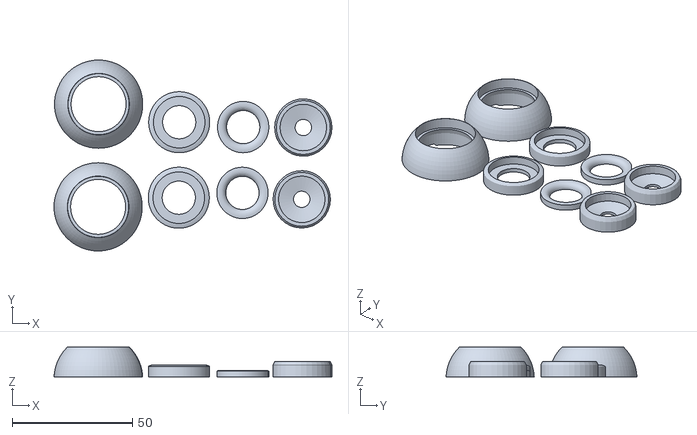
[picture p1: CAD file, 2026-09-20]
Components/3D Components/Robot 3d files/Face Jaw and head/2xEyeBallFullV2.stl
115.5 x 79.4 x 12.5

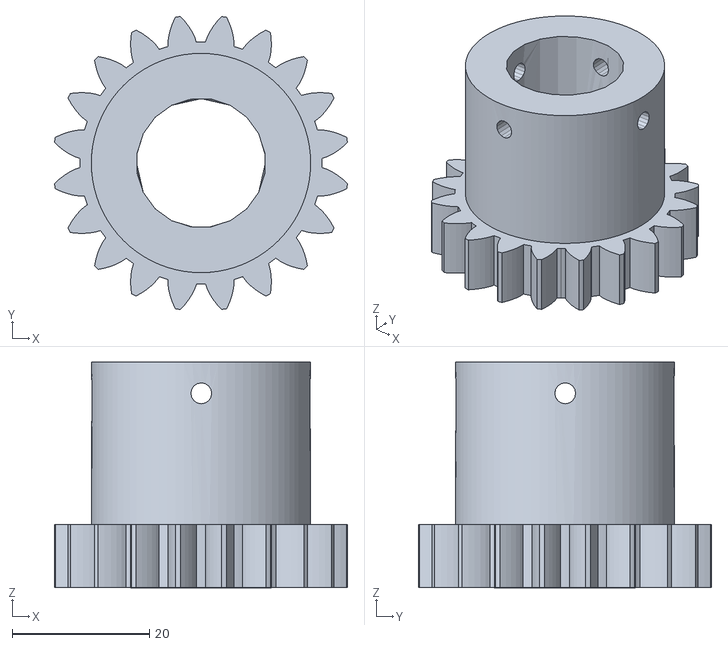
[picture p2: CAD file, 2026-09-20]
Components/3D Components/Robot 3d files/Face Jaw and head/MainGearV2.stl
42.7 x 42.7 x 32.8

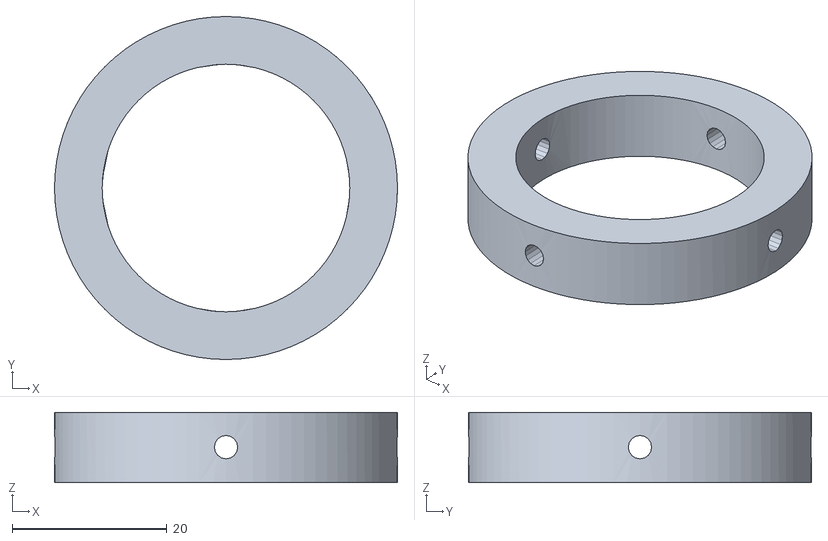
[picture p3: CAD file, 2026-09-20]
Components/3D Components/Robot 3d files/Face Jaw and head/RingV2.stl
44.3 x 44.3 x 9.08

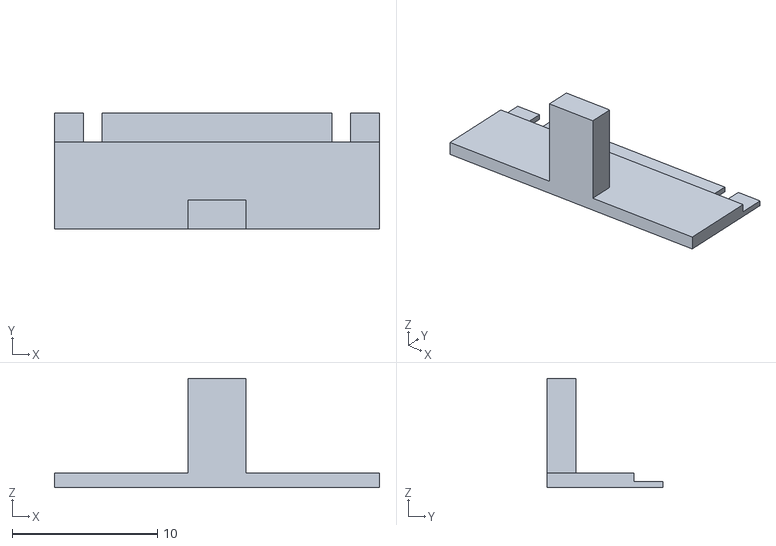
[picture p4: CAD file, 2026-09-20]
Components/3D Components/Robot 3d files/FFC Connector/Random FFC connector/pi-camera-connector-part-v7.stl
22.4 x 8.00 x 7.50

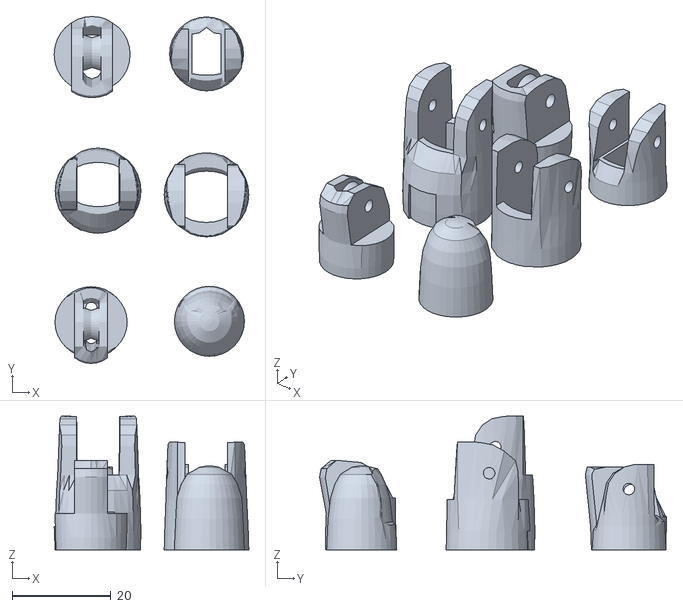
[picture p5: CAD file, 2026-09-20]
Components/3D Components/Robot 3d files/Left Arm/Fingers/Index3.stl
39.4 x 70.2 x 27.0

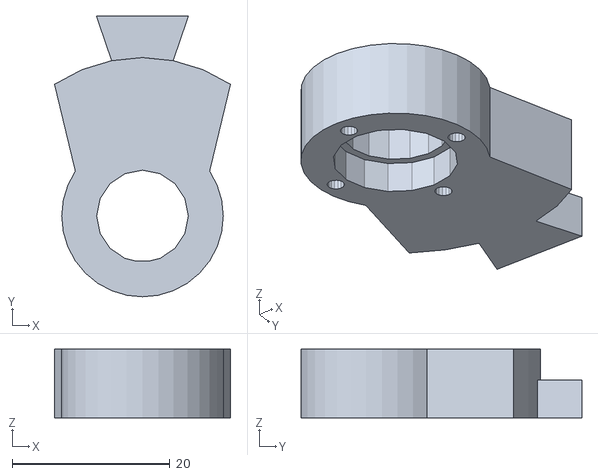
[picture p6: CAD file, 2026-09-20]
Components/3D Components/Robot 3d files/Left Arm/Shoulder and bicep/PivPotentioRoundV3(Copy).stl
22.3 x 35.5 x 8.68

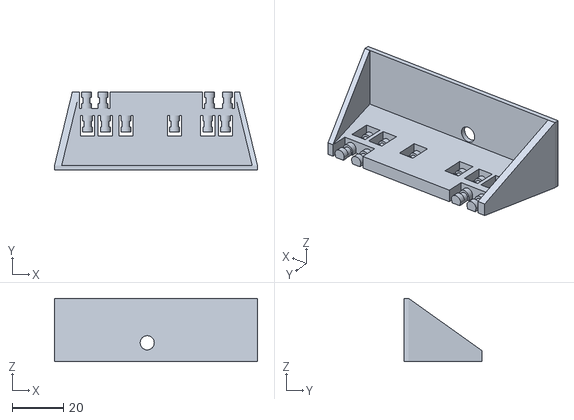
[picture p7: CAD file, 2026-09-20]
Components/3D Components/Robot 3d files/Left Arm/Wrist and Fore arm/LeftTensionerV1.stl
79.3 x 30.3 x 24.7

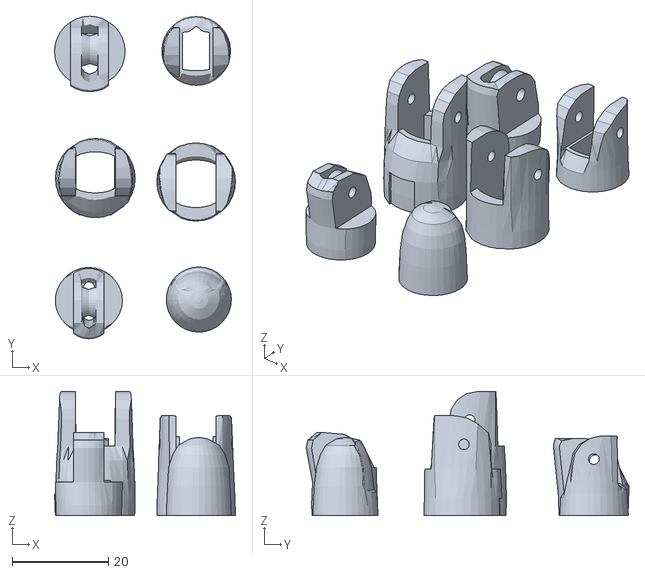
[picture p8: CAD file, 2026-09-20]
Components/3D Components/Robot 3d files/Right Arm/Fingers/ringfinger3.stl
37.6 x 67.0 x 25.8

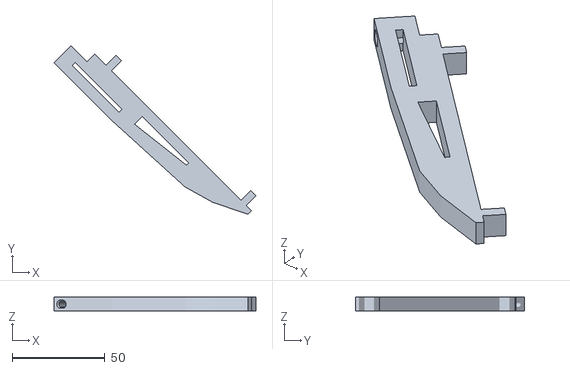
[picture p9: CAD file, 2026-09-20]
Components/3D Components/Robot 3d files/Right Arm/Shoulder and Bicep/ReinforcerV2.stl
108.8 x 90.9 x 7.77

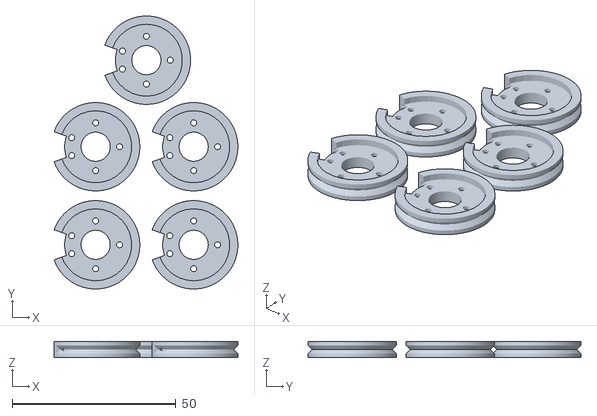
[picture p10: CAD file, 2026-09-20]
Components/3D Components/Robot 3d files/Right Arm/Wrist and Forearm/servo-pulleyX5.stl
56.1 x 83.4 x 5.00

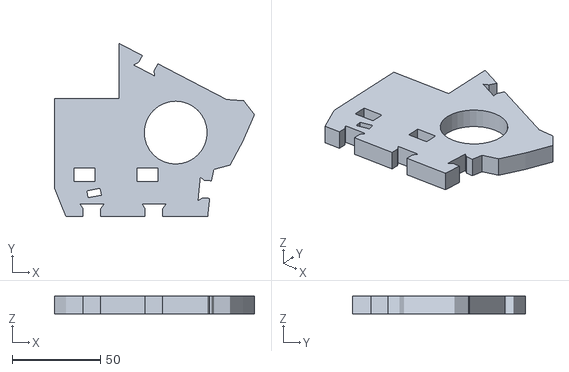
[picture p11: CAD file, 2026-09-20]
Components/3D Components/Robot 3d files/Body/HomLowFront-V1.stl
113.5 x 98.4 x 10.1

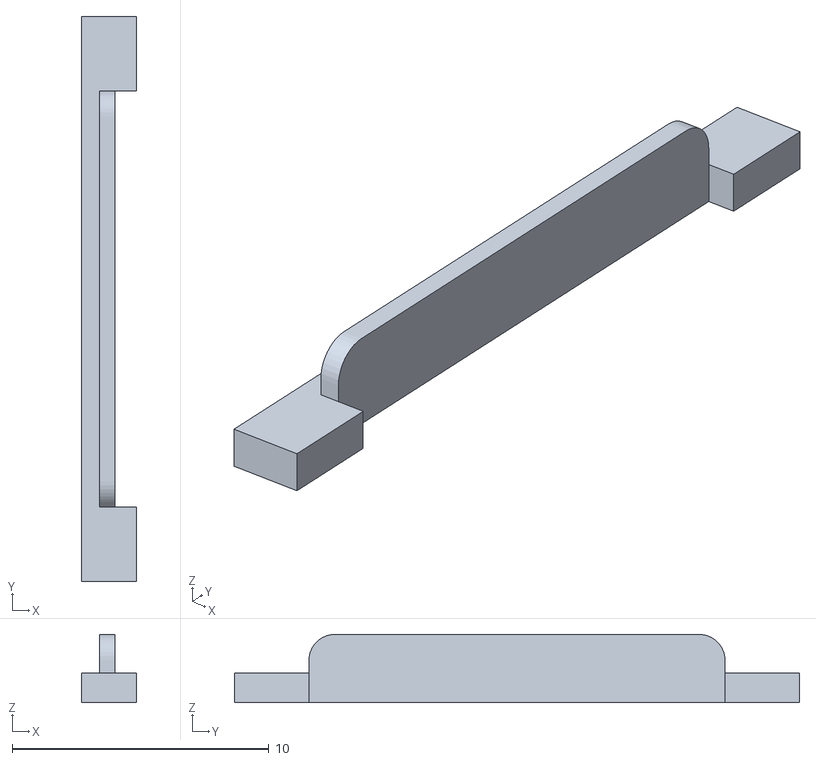
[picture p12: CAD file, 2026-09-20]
Components/3D Components/Robot 3d files/FFC Connector/Random FFC connector/ribbon_clip.stl
2.15 x 22.0 x 2.65

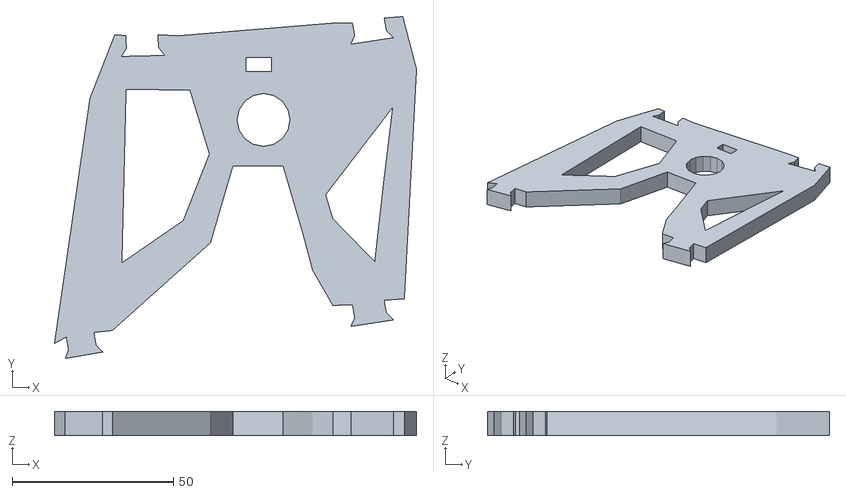
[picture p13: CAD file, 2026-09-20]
Components/3D Components/Robot 3d files/Left Arm/Shoulder and bicep/HighArmSideV3.stl
112.4 x 106.1 x 7.50

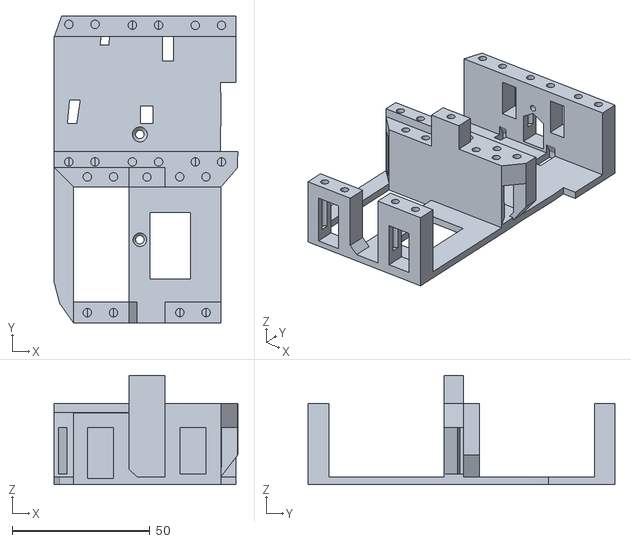
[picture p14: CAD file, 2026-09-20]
Components/3D Components/Robot 3d files/Left Arm/Wrist and Fore arm/LeftRobServoBedV6 black.stl
66.7 x 111.6 x 39.7

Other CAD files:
Components/3D Components/Robot 3d files/Right Arm/Fingers/Auriculaire3.stl
Components/3D Components/Robot 3d files/Right Arm/Shoulder and Bicep/PivConnectorV1.stl
Components/3D Components/Robot 3d files/Right Arm/Wrist and Forearm/robpart4V4.stl
Components/3D Components/Robot 3d files/Body/ClaviBackV2 (1).stl
Components/3D Components/Robot 3d files/Body/ClaviBackV2.stl
Components/3D Components/Robot 3d files/Body/ClaviFrontV2 (1).stl
Components/3D Components/Robot 3d files/Body/ClaviFrontV2.stl
Components/3D Components/Robot 3d files/Body/HomLowBackV3 (1).stl
Components/3D Components/Robot 3d files/Body/HomLowBackV3.stl
Components/3D Components/Robot 3d files/Body/KinectSideBackV2 (1).stl
Components/3D Components/Robot 3d files/Body/KinectSideBackV2.stl
Components/3D Components/Robot 3d files/Body/KinectSideHolderV1 (1).stl
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

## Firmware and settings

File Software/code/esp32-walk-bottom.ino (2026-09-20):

#include <WiFi.h>
#include <WebServer.h>

// WiFi credentials
const char* ssid = "ESP32_Robot";
const char* password = "12345678";

WebServer server(80);

// Motor pins
#define R_RPWM 19
#define R_LPWM 21
#define L_RPWM 22
#define L_LPWM 23

int speedVal = 0; // -255 to 255
int steerVal = 0; // -100 to 100
String currentDir = "stop";

// Security system
unsigned long lastClientCheck = 0;
const unsigned long CLIENT_CHECK_INTERVAL = 500;
int connectedClients = 0;
bool motorsEnabled = false;

// --- Helper Functions ---
void setMotorSpeeds(int leftSpeed, int rightSpeed, bool forward) {
  if (!motorsEnabled) {
    analogWrite(L_RPWM, 0);
    analogWrite(L_LPWM, 0);
    analogWrite(R_RPWM, 0);
    analogWrite(R_LPWM, 0);
    return;
  }

  leftSpeed = constrain(leftSpeed, 0, 255);
  rightSpeed = constrain(rightSpeed, 0, 255);

  if (forward) {
    analogWrite(L_RPWM, leftSpeed);
    analogWrite(L_LPWM, 0);
    analogWrite(R_RPWM, 0);
    analogWrite(R_LPWM, rightSpeed);
  } else {
    analogWrite(L_RPWM, 0);
    analogWrite(L_LPWM, leftSpeed);
    analogWrite(R_RPWM, rightSpeed);
    analogWrite(R_LPWM, 0);
  }
}

void stopMotors() {
  analogWrite(R_RPWM, 0);
  analogWrite(R_LPWM, 0);
  analogWrite(L_RPWM, 0);
  analogWrite(L_LPWM, 0);
  currentDir = "stop";
  speedVal = 0;
  steerVal = 0;
}

// --- Driving Logic ---
void drive(int speed, int steer) {
  if (speed == 0) {
    stopMotors();
    return;
  }

  bool forward = speed > 0;
  int absSpeed = abs(speed);

  float leftFactor = 1.0, rightFactor = 1.0;
  if (steer > 0) leftFactor = 1.0 - (steer / 100.0);
  else if (steer < 0) rightFactor = 1.0 - (abs(steer) / 100.0);

  int leftSpeed = absSpeed * leftFactor;
  int rightSpeed = absSpeed * rightFactor;

  setMotorSpeeds(leftSpeed, rightSpeed, forward);
  currentDir = forward ? "forward" : "backward";
}

// --- Security ---
void checkConnectedClients() {
  connectedClients = WiFi.softAPgetStationNum();
  if (connectedClients == 0 && motorsEnabled) {
    motorsEnabled = false;
    stopMotors();
    Serial.println("SECURITY: No clients connected - Motors STOPPED");
  } else if (connectedClients > 0 && !motorsEnabled) {
    motorsEnabled = true;
    Serial.print("SECURITY: Client connected - Motors ENABLED (");
    Serial.print(connectedClients);
    Serial.println(" client(s))");
  }
}

// --- Web Page ---
void handleRoot() {
  String html = R"rawliteral(
<html>
<head>
<title>ESP32 Robot Dual Joystick</title>
<meta name="viewport" content="width=device-width, initial-scale=1">
<style>
body{text-align:center;background:#f2f2f2;font-family:Arial;padding:20px;}
.security-status{background:#4CAF50;color:white;padding:10px;border-radius:5px;margin-bottom:20px;font-weight:bold;}
.container{display:flex;justify-content:center;align-items:center;gap:30px;flex-wrap:wrap;}
.joystick-wrapper{text-align:center;}
canvas{background:#ddd;border-radius:10px;touch-action:none;margin:10px;}
h2{color:#333;}h4{color:#666;margin:5px;}
.status{margin-top:20px;font-size:18px;color:#333;}
.emergency-btn{background:red;color:white;font-weight:bold;padding:15px 30px;border:none;border-radius:10px;font-size:18px;cursor:pointer;margin-top:20px;}
.emergency-btn:hover{background:#cc0000;}
</style>
</head>
<body>
<h2>ESP32 Robot Dual Joystick Control</h2>
<div class="security-status">🔒 Security System Active - Connection Verified</div>

<div class="container">
<div class="joystick-wrapper">
<h4>Speed Control</h4>
<canvas id="speedJoystick" width="200" height="300"></canvas>
</div>
<div class="joystick-wrapper">
<h4>Steering Control</h4>
<canvas id="steerJoystick" width="300" height="200"></canvas>
</div>
</div>

<button class="emergency-btn" onclick="emergencyStop()">EMERGENCY STOP</button>

<div class="status">
<h3>Speed: <span id="sp">0</span> | Steering: <span id="st">0</span></h3>
</div>

<script>
let currentSpeed=0,currentSteer=0,lastSend=0;

// Emergency stop
function emergencyStop(){
  currentSpeed=0;currentSteer=0;
  document.getElementById('sp').innerText=0;
  document.getElementById('st').innerText=0;
  fetch('/emergencystop');
}

// Joystick variables
const speedCanvas=document.getElementById('speedJoystick');
const steerCanvas=document.getElementById('steerJoystick');

const speedCtx=speedCanvas.getContext('2d');
const steerCtx=steerCanvas.getContext('2d');

const speedCenter={x:speedCanvas.width/2,y:speedCanvas.height/2};
const steerCenter={x:steerCanvas.width/2,y:steerCanvas.height/2};

const speedTrackHeight=250,speedKnobRadius=25;
const steerTrackWidth=250,steerKnobRadius=25;

let speedKnob={x:speedCenter.x,y:speedCenter.y};
let steerKnob={x:steerCenter.x,y:steerCenter.y};

let speedDragging=false,steerDragging=false;

// Draw functions
function drawSpeedJoystick(){
  speedCtx.clearRect(0,0,speedCanvas.width,speedCanvas.height);
  speedCtx.fillStyle="#ccc";
  speedCtx.fillRect(speedCenter.x-30,speedCenter.y-125,60,250);
  speedCtx.strokeStyle="#999"; speedCtx.lineWidth=2;
  speedCtx.beginPath();
  speedCtx.moveTo(speedCenter.x-40,speedCenter.y); speedCtx.lineTo(speedCenter.x+40,speedCenter.y);
  speedCtx.stroke();
  speedCtx.beginPath(); speedCtx.arc(speedKnob.x,speedKnob.y,speedKnobRadius,0,Math.PI*2);
  speedCtx.fillStyle="#4CAF50"; speedCtx.fill();
  speedCtx.strokeStyle="#333"; speedCtx.lineWidth=2; speedCtx.stroke();
}

function drawSteerJoystick(){
  steerCtx.clearRect(0,0,steerCanvas.width,steerCanvas.height);
  steerCtx.fillStyle="#ccc";
  steerCtx.fillRect(steerCenter.x-125,steerCenter.y-30,250,60);
  steerCtx.strokeStyle="#999"; steerCtx.lineWidth=2;
  steerCtx.beginPath();
  steerCtx.moveTo(steerCenter.x,steerCenter.y-40); steerCtx.lineTo(steerCenter.x,steerCenter.y+40);
  steerCtx.stroke();
  steerCtx.beginPath(); steerCtx.arc(steerKnob.x,steerKnob.y,steerKnobRadius,0,Math.PI*2);
  steerCtx.fillStyle="#2196F3"; steerCtx.fill();
  steerCtx.strokeStyle="#333"; steerCtx.lineWidth=2; steerCtx.stroke();
}

// Send joystick values
function sendControl(){
  document.getElementById('sp').innerText=currentSpeed;
  document.getElementById('st').innerText=currentSteer;
  const now=Date.now();
  if(now-lastSend>50){
    fetch(`/joystick?speed=${currentSpeed}&steer=${currentSteer}`);
    lastSend=now;
  }
}

// Speed joystick events
function moveSpeedKnob(e){
  const rect=speedCanvas.getBoundingClientRect();
  const y=e.clientY-rect.top;
  speedKnob.x=speedCenter.x;
  speedKnob.y=Math.max(speedCenter.y-125+speedKnobRadius,Math.min(y,speedCenter.y+125-speedKnobRadius));
  const dy=speedCenter.y-speedKnob.y;
  currentSpeed=Math.round((dy/125)*255);
  drawSpeedJoystick(); sendControl();
}
speedCanvas.addEventListener('pointerdown',e=>{speedDragging=true; moveSpeedKnob(e);});
speedCanvas.addEventListener('pointermove',e=>{if(speedDragging) moveSpeedKnob(e);});
speedCanvas.addEventListener('pointerup',e=>{speedDragging=false; speedKnob={x:speedCenter.x,y:speedCenter.y}; currentSpeed=0; drawSpeedJoystick(); sendControl();});
speedCanvas.addEventListener('pointerleave',e=>{speedDragging=false; speedKnob={x:speedCenter.x,y:speedCenter.y}; currentSpeed=0; drawSpeedJoystick(); sendControl();});

// Steering joystick events
function moveSteerKnob(e){
  const rect=steerCanvas.getBoundingClientRect();
  const x=e.clientX-rect.left;
  steerKnob.y=steerCenter.y;
  steerKnob.x=Math.max(steerCenter.x-125+steerKnobRadius,Math.min(x,steerCenter.x+125-steerKnobRadius));
  const dx=steerKnob.x-steerCenter.x;
  currentSteer=Math.round((dx/125)*100);
  drawSteerJoystick(); sendControl();
}
steerCanvas.addEventListener('pointerdown',e=>{steerDragging=true; moveSteerKnob(e);});
steerCanvas.addEventListener('pointermove',e=>{if(steerDragging) moveSteerKnob(e);});
steerCanvas.addEventListener('pointerup',e=>{steerDragging=false; steerKnob={x:steerCenter.x,y:steerCenter.y}; currentSteer=0; drawSteerJoystick(); sendControl();});
steerCanvas.addEventListener('pointerleave',e=>{steerDragging=false; steerKnob={x:steerCenter.x,y:steerCenter.y}; currentSteer=0; drawSteerJoystick(); sendControl();});

// Initial draw
drawSpeedJoystick();
drawSteerJoystick();
</script>
</body>
</html>
)rawliteral";

  server.send(200,"text/html",html);
}

// --- Setup ---
void setup() {
  Serial.begin(115200);

  pinMode(R_RPWM, OUTPUT);
  pinMode(R_LPWM, OUTPUT);
  pinMode(L_RPWM, OUTPUT);
  pinMode(L_LPWM, OUTPUT);
  stopMotors();

  WiFi.softAP(ssid,password);
  Serial.println("WiFi AP started");
  Serial.print("IP: "); Serial.println(WiFi.softAPIP());
  Serial.println("SECURITY: Waiting for client connection...");

  server.on("/", handleRoot);

  server.on("/joystick",[](){
    if(server.hasArg("speed") && server.hasArg("steer")){
      int s=constrain(server.arg("speed").toInt(),-255,255);
      int t=constrain(server.arg("steer").toInt(),-100,100);
      speedVal=s; steerVal=t;
      drive(speedVal,steerVal);
    }
    server.send(200,"text/plain","OK");
  });

  server.on("/emergencystop",[](){
    stopMotors();
    server.send(200,"text/plain","EMERGENCY STOP ACTIVATED");
    Serial.println("EMERGENCY STOP triggered!");
  });

  server.on("/status",[](){
    String json="{\"clients\":"+String(connectedClients)+",\"enabled\":"+String(motorsEnabled)+"}";
    server.send(200,"application/json",json);
  });

  server.begin();
  Serial.println("Server started");
}

// --- Loop ---
void loop(){
  server.handleClient();

  if(millis()-lastClientCheck>=CLIENT_CHECK_INTERVAL){
    lastClientCheck=millis();
    checkConnectedClients();
  }

  if(Serial.available()){
    String cmd=Serial.readStringUntil('\n');
    cmd.trim(); cmd.toLowerCase();

    if(cmd=="status"){
      Serial.print("Connected clients: "); Serial.print(connectedClients);
      Serial.print(" | Motors: "); Serial.println(motorsEnabled?"ENABLED":"DISABLED");
    } else if(!motorsEnabled){
      Serial.println("WARNING: No clients connected - Motors disabled for safety!");
    } else if(cmd=="stop") stopMotors();
    else if(cmd.startsWith("speed ")){
      int val=constrain(cmd.substring(6).toInt(),-255,255);
      speedVal=val; drive(speedVal,steerVal);
    } else if(cmd.startsWith("steer ")){
      int val=constrain(cmd.substring(6).toInt(),-100,100);
      steerVal=val; drive(speedVal,steerVal);
    } else if(cmd.startsWith("move ")){
      int comma=cmd.indexOf(',');
      if(comma!=-1){
        int s=constrain(cmd.substring(5,comma).toInt(),-255,255);
        int t=constrain(cmd.substring(comma+1).toInt(),-100,100);
        speedVal=s; steerVal=t; drive(speedVal,steerVal);
      }
    } else Serial.println("Commands: stop | speed <val> | steer <val> | move <speed,steer> | status");
  }
}

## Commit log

2026-09-18 docs(electronics): add power distribution and hardware documentation
2026-09-18 docs(mechanical): add hybrid chassis design and mobility documentation
2026-09-18 docs(electronics): expand power distribution and wiring documentation
2026-09-18 docs(mechanical): update hybrid chassis design and future improvements
2026-09-20 Add 3d files to SRC
    [2xEyeBallFullV2.stl, Auriculaire3.stl, Bolt_entretoise7 Black.stl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]
2026-09-20 feat: add ESP32 and ESP8266 firmware code for face, walk, and hand control
